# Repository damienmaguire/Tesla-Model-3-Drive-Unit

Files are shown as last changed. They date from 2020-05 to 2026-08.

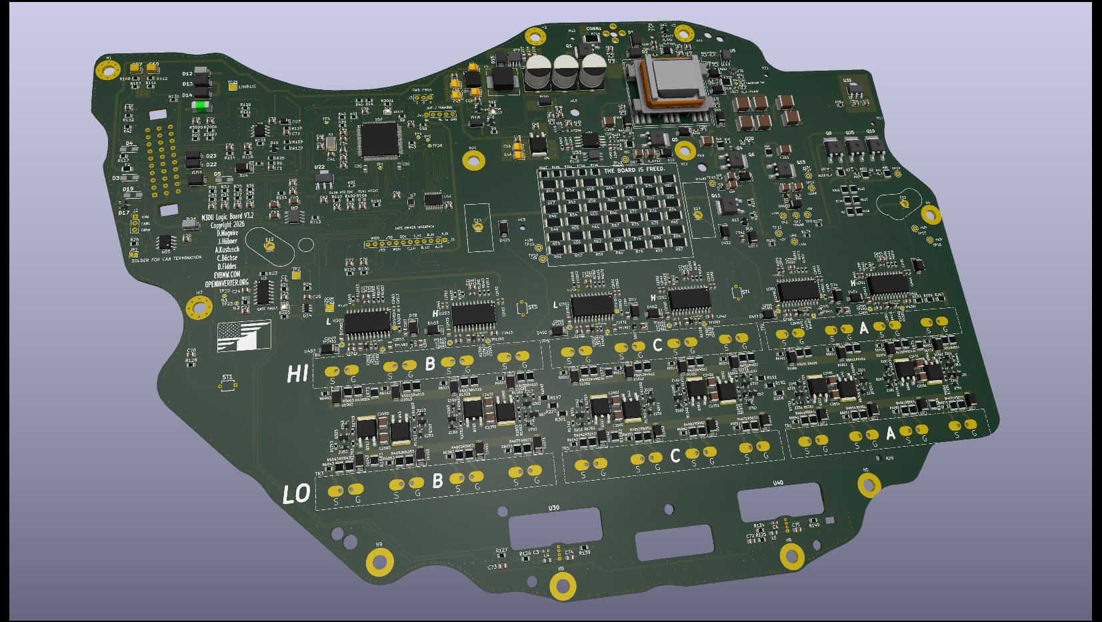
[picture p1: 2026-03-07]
Design/M3DU_BoardV3_2/M3DU_BoardV3_2.jpg

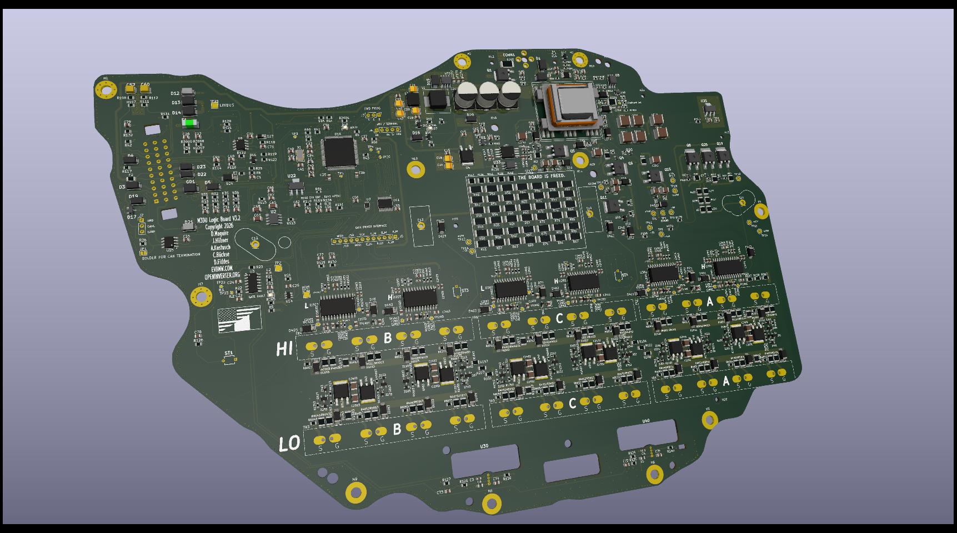
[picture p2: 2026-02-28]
Design/M3DU_BoardV3_2/Production/M3DU_BoardV3_2_3d.jpg

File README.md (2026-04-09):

# Tesla-Model-3-Drive-Unit
Open Source logic board for the Tesla Model 3 rear drive unit. PCB Files in DesignSpark 9 and Kicad 8 format.Based on the inverter designed by Johannes Heubner using FOC control.
<br>
Screenshot from 2025-01-08 18-51-52

<br>
13/03/20 : Added CAN logs from both CAN busses from the rear drive unit inverter powered on the bench.

04/05/20 : Added pdf schematic and board layout for the V1 logic board design. Untested as of this date. Given recent developments the design files will not be released at this time. For more information see : <br>
https://openinverter.org/forum/viewtopic.php?f=10&t=575

26/07/20 : After initial testing of V1 in a rear drive unit inverter some issues were found. V2 now released. Changes :

-Added resolver signal preconditioning circuit. Resolver signal needs to be amplified to 1v p-p and offset to 1.6v before feeding to the Tesla resolvver power amp.

-Added opamp to combine differential HV voltage measurement to unipolar.

-Deleted Tagconnect Jtag.

-Added 3v3 pin for single wire programming via st-link.

-Added solder jumper for optional single 5v power supply.

Please note design source files will be only available via Patreon for a period of time:

https://www.patreon.com/evbmw

02/10/20 : V2 board now fully tested in an M3 Rear drive unit and working very well on the bench.
<br>At this time I have decided to do a full opensource release of all design sources:)
<br>More updates and video to following including testing in a M3 front DU.

18/11/20 : Uploaded spreadsheet work in progress for mapping the pin assignments of the TMS320F28377D MCU.

21/11/20 : Discovered an eeprom on the back of the pcb. Logic analyser captures uploaded. All logic analyser captures made using Saleae logic. Free software available here :https://www.saleae.com/downloads/

02/12/20 : Big thanks to Colin Kidder (https://github.com/collin80) for the explanation of the STGAP1AS SPI gate driver traffic. PDF uploaded to the Gate SPI folder.

11/12/20 : Big thanks again to Colin Kidder (https://github.com/collin80) for the explanation of the TLF SPI power supply traffic. PDF uploaded to the TLF SPI folder.

08/02/21 : We have a new modboard : https://vimeo.com/509198907

08/05/21 : Added V3 modboard pdf schematic and board layout. Turns out Mr.Musk almost made a fool of me....again! 

18/10/21 : Added design files for USB to JTAG adapter board.

19/03/23 : Add first temp sensor calibration data

30/03/23 : Running : https://vimeo.com/809120859

15/08/24 : Added a very early schematic of the gate driver section for use in the PCB replacement project.

24/10/24 : Updated schematic of the gate driver power supply section for use in the PCB replacement project.

17/01/25 : Updated schematic and PCB layout to latest "complete" V1 version.

07/05/25 : First prototypes undergoing test.

board_jlc_powerup

28/05/25 : Testing continues. First motor spins :

https://youtu.be/JKbsiIRJ8mo

29/09/25 : V2 board now runs on HV : https://vimeo.com/1122427765

Added V3 Schematic and board layout.

26/10/25 : The V3 works. https://youtu.be/QYh9N8k0tf8

18/11/25 : First in car tests : https://youtu.be/6yrDDHRgUPQ also added pinout diagram.

03/12/25 : Updated 30 pin connector pinout and added a DXF of the OEM board derived from a laser scan.

01/02/26 : Uploaded V3.2 schematic and pcb layout. First order of boards on the way!

26/02/26 : Added capture of the gate driver SPI from a Model 3 front drive unit inverter.

28/02/26 : V3.2 board now undergoing testing.
V32_1

07/03/26 : I have made the decision to fully opensource the V3.2 design. Almost six years of work in here by myself and others so please respect that.

09/04/26 : An amazing contribution : https://github.com/jrbe/Tesla-Model-3-Current-Sensor-Block
           Prototypes on order.

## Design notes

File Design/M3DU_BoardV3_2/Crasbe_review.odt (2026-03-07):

M3 PCB Crasbe Review

personally, I'm not a big fan of SMD fuses. I can't tell from the screenshot, but if you have space (haha), it might be good to add an SMD fuse socket.

the value of the Zener diode D20 (7V) might be a bit high for the 3.3V rail.

the value of the inductor L3 is incorrect for the 3.3V rail, the datasheet says it should be 47µH.

the values of some capacitors do not follow the naming scheme: C124, C275, C282, C286, C334 have the value "0.1uF" while most use "100nF". this causes a BOM inconsistency.

some capacitors use symbols for polarized caps while they probably aren't polarized: C29, C30, C31, C32, C39, C40, C58, C59, C61, C62, C64, C66, C67, C69, C72, C73, C79.

(nitpicky) the schematic would be a bit easier to read if IC2 was mirrored.

typo in the "DC BUS DISCH AND VOLTAGE MEASURE" box: "HV Duscharge ..." instead of "HV Discharge ...".

in the "DC BUS DISCH AND VOLTAGE MEASURE" box: maybe you could add a dotted line or something to designate the HV and the isolated section more clearly.

not sure if that's the original Tesla design, but the "Motor Temp Sensor" voltage divider seems odd. assuming a 100k NTC, you'd have 0.275V at 25°C and something like 1.0V at 80°C. that's not using the full scale of the ADC and therefore reduces the resolution

general remark: you can set the direction of labels in KiCAD, that would make it easier to follow for signals like "SINB" and "ENC_A"

general remark: the ERC check in KiCAD will bonk you for not putting the blue "unused" crosses on usused pins. while it's not a good idea to put them on for example the microcontroller pins when you still might use them, it's good practice to put them on "NC" or "TEST" pins

for the PCB:

- TP12 and TP14 are quite close to the HV. even though they are on the "hot" side, I'd move them farther away from the resistors. As they are connected to the internal planes anyway, you can position them close to anywhere
- the isolation distance of the big resistor array to the "cold" side in general is on the small side
- TP2, TP4, TP5 are SMD test points, I'd change that to THT test points, there is enough space
- U3, U5, U303, U293, U302, U292, U301, U291, ... have adjacent pins that are connected and you connected them in the center of the pad. PCB assemblers often don't like that (both the Chinese and private persons) because it's hard to tell whether you have a short or it was intentionally connected. A better solution is the green trace on the upper right of picture [1]
- U3, U8, U31, U33, ... have traces leaving at a 90° angle from the pad. This is not good practise either (see picture [1] in the lower half)
- under/near U16 are three very small vias. There is enough space to make them the same size as all other vias. That might save some money (not sure if they are small enough to cost extra yet)
- the layout around the two step down converters U22 and U70 is not great. In order to minimize EMC, the area and current paths of the step downs has to be reduced. See [2]
- the length of the current sensor traces to the comparator might be an issue, especially since they are going past "noisy" areas. I'm not sure if it would be better to place LM2091 closer to the sensors, but then you'd have long lines for the OCURLIM_POS and OCURLIM_NEG lines. However these are "digital" until they are filtered, while the current signals are analog

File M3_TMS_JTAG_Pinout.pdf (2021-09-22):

# Tesla Model 3 Inverter JTAG Connection

Board Connector: Hirose DF20F-10DP-1V(55)
Cable Connector Shell: Hirose DF20A-10DS-1C
Cable Connector Pins: Hirose DF20F-2830SCFA

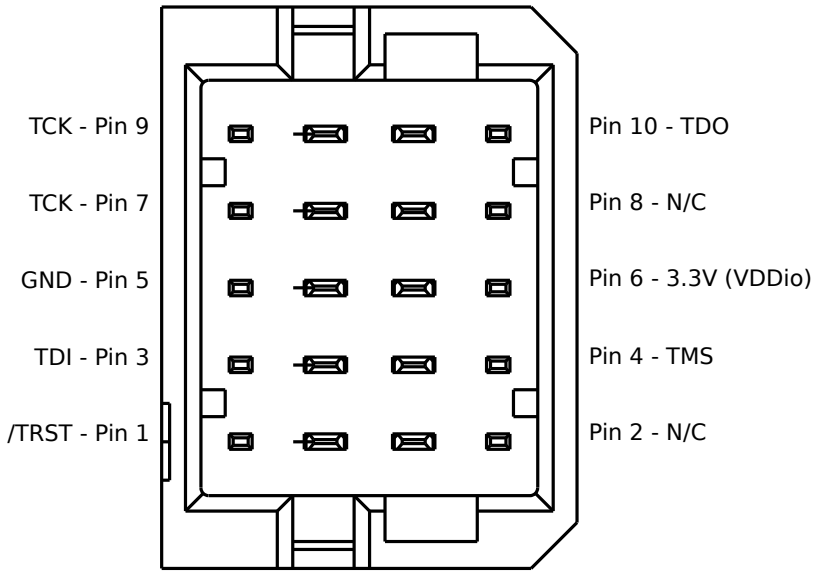
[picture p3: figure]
TCK - Pin 9; TCK - Pin 7; Pin 10 - TDO; Pin 8 - N/C; GND - Pin 5; TDI - Pin 3; /TRST - Pin 1; Pin 6 - 3.3V (VDDio); Pin 4 - TMS; Pin 2 - N/C

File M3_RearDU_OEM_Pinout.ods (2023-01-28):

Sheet: Main_Conn
Model 3 X090 Rear Inverter Connector OEM
Pin | Signal | Tesla Wiring Harness Colour | Connector Pin Numbering
1 | Proximity Digital in (charge port) | White | (looking at wiring harness connector,
2 | Vehicle CAN L | Blue | cable exiting to the bottom)
3 | Switched +12v | Yellow
4 | HVIL OUT | White | 10 | 20 | 30
5 | Accel 2 Ground | Violet | 9 | 19 | 29
6 | Accel 1 Ground | Yellow | 8 | 18 | 28
7 | Resolver SIN - | Red | 7 | 17 | 27
8 | Resolver COS + | Violet | 6 | 16 | 26
9 | N/C |  | 5 | 15 | 25
10 | LIN Oil Pump status | Yellow | 4 | 14 | 24
11 | Brake NO Digital in | Red | 3 | 13 | 23
12 | Vehicle CAN H | Yellow | 2 | 12 | 22
13 | Ground | Black | 1 | 11 | 21
14 | +5v Out 2 | Brown
15 | +5v Out 1 | Red
16 | Resolver EXC - | Black
17 | Resolver SIN + | Green
18 | Stator Temp - | Grey
19 | N/C
20 | PRTY – CAN L | White
21 | Brake NC Digital in | Brown
22 | Unswitched +12v | Violet
23 | HVIL IN | Red
24 | Accel 2 | Green
25 | Accel 1 | Grey
26 | Resolver EXC+ | Yellow
27 | Resolver COS - | Blue
28 | Stator Temp + | White
29 | N/C
30 | PRTY – CAN H | Blue

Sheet: Oil_Pump
Model 3 X092 Rear InverterOil Pump Connector OEM
Pin | Signal | Tesla Wiring Harness Colour | Connector Pin Numbering
1 | +12V In | Red | (looking at wiring harness connector,
2 | LIN | Yellow | cable exiting to the bottom)
3 | GND | Black
 |  |  | 3
 |  |  | 2
 |  |  | 1

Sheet: Resolver
Model 3 X091 Rear Inverter Resolver Connector OEM
Pin | Signal | Tesla Wiring Harness Colour | Connector Pin Numbering
1 | Temp+ | White | (looking at wiring harness connector,
2 |  |  | cable exiting to the bottom)
3 | Exc+ | Yellow
4 | Sin+ | Green
5 | Cos+ | Vilot
6 | Temp- | Grey
7
8 | Exc- | Black
9 | Sin- | Red | 5 | 10
10 | Cos- | Blue | 4 | 9
 |  |  | 3 | 8
 |  |  | 2 | 7
 |  |  | 1 | 6

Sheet: Throttle
Model 3 X167 Rear Inverter Throttle Connector OEM
Pin | Signal | Tesla Wiring Harness Colour | Connector Pin Numbering
1 | +5V Accel2 | Brown | (looking at wiring harness connector,
2 | Accel Sig 2 | Green | cable exiting to the bottom)
3 | Gnd Accel 2 | Vilot
4 | GND Accel 1 | Yellow
5 | Accel Sig 1 | Grey
6 | +5V Accel 1 | Red
 |  |  | 6
 |  |  | 5
 |  |  | 4
 |  |  | 3
 |  |  | 2
 |  |  | 1

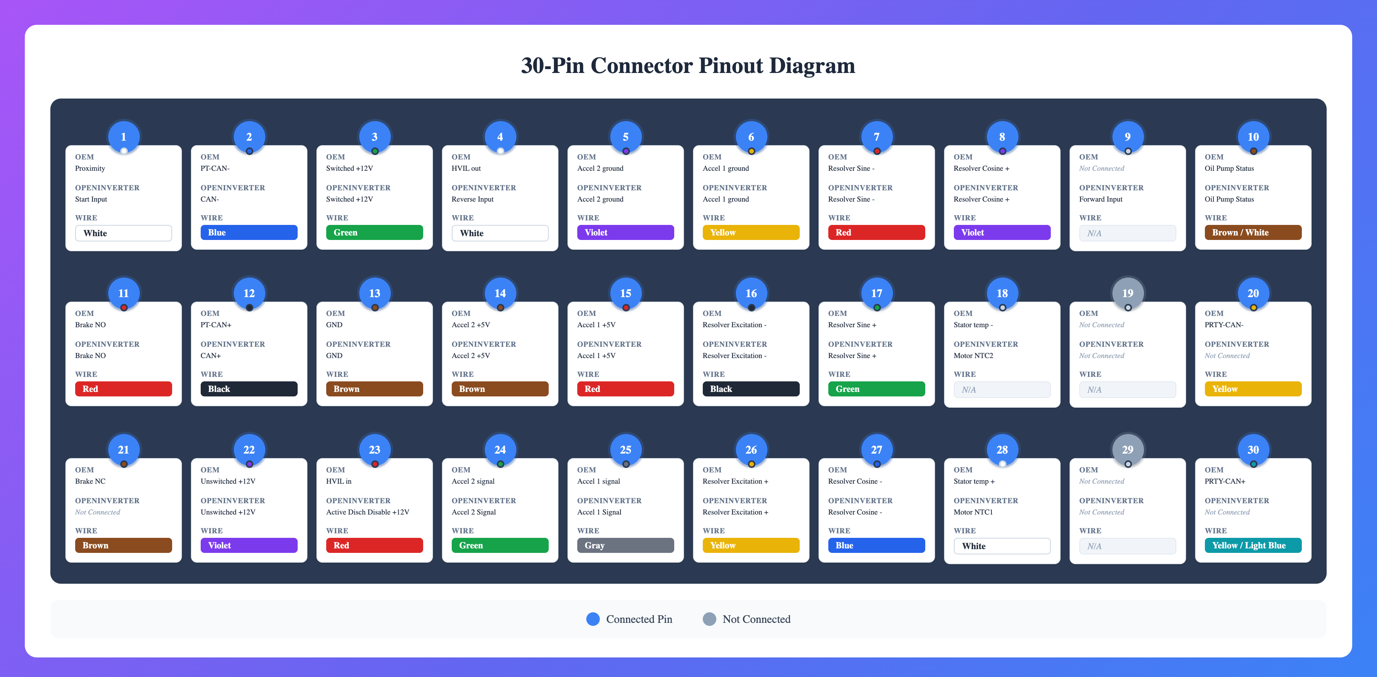
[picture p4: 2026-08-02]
OI_Pinout.png

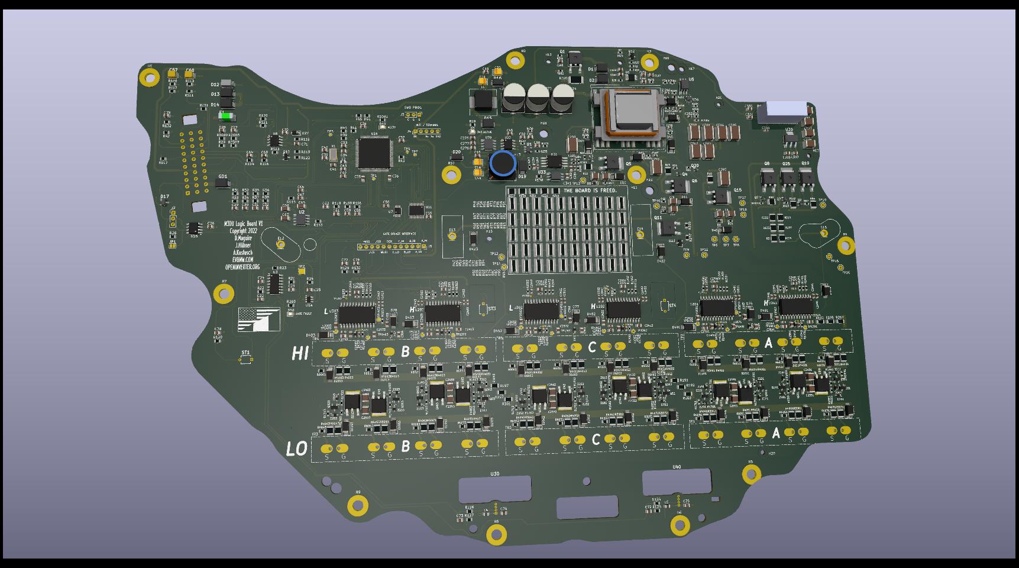
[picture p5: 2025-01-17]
Design/M3DUBoard_V1.jpg

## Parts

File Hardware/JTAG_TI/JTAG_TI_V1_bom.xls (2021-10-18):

Comment | Designator | Footprint | LCSC Part #
93LC56BT-I/SN | IC4 | SOIC-8_3.9x4.9x1.27P | C6164
AMS117-3.3V | IC2 | SOT-223 | C6186
36pF | C9,C10 | C0805 | C1816
3u3 | C6 | C0805 | C159781
4u7 | C7,C8 | C0805 | C98195
10uF | C1,C12 | C0805 | C15850
0.1uF | C3,C4,C5,C11 | C0805 | C49678
FT2232HL-REEL | IC1 | LQFP-64_10.0x10.0x0.5P | C27882
12MHz | Y1 | SMD-CRY-3.8x13.5_2P | C111117
RED LED | LED1,LED2,LED3 | LED_0805 | C84256
1KΩ | R5,R17 | 0805_R | C17513
2.2KΩ | R9 | 0805_R | C17520
10KΩ | R8 | 0805_R | C17414
12KΩ | R4 | 0805_R | C17444
680Ω | R1,R2,R3 | 0805_R | C17798
100UF 6.3V | C2 | CASE-B_3528 | C16133
CG0603MLC-05E | R6,R7 | 0603 | C20965
MH2029-300Y | L1,L2 | 0805_L | C281113

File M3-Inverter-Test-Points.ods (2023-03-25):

Test Point | Location | Description | Purpose
TP1 |  |  | Unknown | Key
TP2 |  |  | Unknown | Unknown | Nothing understood about this TP yet
TP3 |  |  | Unknown | Mapped | Location identified and something about the signal is known
TP4 |  |  | Unknown | Known | The purpose and signal on the TP is fully known and documented
TP5 |  |  | Unknown
TP6 |  |  | Unknown
TP7 |  |  | Unknown
TP8 |  |  | Unknown
TP9 |  |  | Unknown
TP10 |  |  | Unknown
TP11 |  |  | Unknown
TP12 |  |  | Unknown
TP13 |  |  | Unknown
TP14 |  |  | Unknown
TP15 |  |  | Unknown
TP16 |  |  | Unknown
TP17 |  |  | Unknown
TP18 |  |  | Unknown
TP19 |  |  | Unknown
TP20 |  |  | Unknown
TP21 |  |  | Unknown
TP22 |  |  | Unknown
TP23 |  |  | Unknown
TP24 |  |  | Unknown
TP25 |  |  | Unknown
TP26 |  |  | Unknown
TP27 | MCU/JTAG | SN74LVC8T245 /OE PWM GATE DRIVER BUFFER CONTROL | Known
TP28 | T1 Gate PSU | GATE DRIVE PSU READY opto output (active low) | Known
TP29 |  |  | Unknown
TP30 | PMIC | 3.3V VDD-IO | Known
TP31 |  |  | Unknown
TP32 | PMIC | Observed with solid 3.3V | Mapped
TP33 |  |  | Unknown
TP34 | PMIC | Observed with 5.5V | Mapped
TP35 | PMIC | Observed with 5V | Mapped
TP36 |  |  | Unknown
TP37 |  |  | Unknown
TP38 | PMIC | Observed with 0.5V | Mapped
TP39 |  |  | Unknown
TP40 |  |  | Unknown
TP41 | PMIC | Observed with 1.17V likely Vcore for MCU | Mapped
TP42 |  |  | Unknown
TP43 | MCU | GPIO83 GATE DRIVE PSU READY (active low) | Known
TP44 |  |  | Unknown
TP45 |  |  | Unknown
TP46 |  |  | Unknown
TP47 |  |  | Unknown
TP48 |  |  | Unknown
TP49 |  |  | Unknown
TP50 | MCU | GPIO1_EPWM1B_SCLA | Mapped
TP51 |  |  | Unknown
TP52 |  |  | Unknown
TP53 |  |  | Unknown
TP54 |  |  | Unknown
TP55 |  |  | Unknown
TP56 |  |  | Unknown
TP57 |  |  | Unknown
TP58 | Phase C U292 | Gate Drive Shutdown (/SD) | Known
TP59 | MCU | GPIO3_EPWM2B_SCLB | Mapped
TP60 |  |  | Unknown
TP61 |  |  | Unknown
TP62 |  |  | Unknown
TP63 |  |  | Unknown
TP64 |  |  | Unknown
TP65 |  |  | Unknown
TP66 | MCU | GPIO69 | Mapped
TP67 | MCU | GPIO70 | Mapped
TP68 | MCU | GPIO71 | Mapped
TP69 | MCU | GPIO73 | Mapped
TP70 | MCU | GPIO80 | Mapped
TP71 | MCU | GPIO79 | Mapped
TP72 | MCU | GPIO81 | Mapped
TP73 | MCU | GPIO82 ENABLE ISOLATED GATE DRIVE PSU | Known
TP74 |  |  | Unknown
TP75 | MCU | GPIO85_SCIRXDA | Mapped
TP76 | MCU | GPIO86_SCITXDB | Mapped
TP77 | MCU | GPIO87_SCIRXDB | Mapped
TP78 | MCU | GPIO88 | Mapped
TP79 | MCU | GPIO89_SCITXDC | Mapped
TP80 | MCU | GPIO90_SCIRXDC | Mapped
TP81 | MCU | GPIO91_SDAA | Mapped
TP82 | MCU | GPIO92_SCLA | Mapped
TP83 | MCU | GPIO93_SCITXDD | Mapped
TP84 | MCU | GPIO94_SCIRXDD | Mapped
TP85 |  |  | Unknown
TP86 |  |  | Unknown
TP87 |  |  | Unknown
TP88 |  |  | Unknown
TP89 |  |  | Unknown
TP90 |  |  | Unknown
TP91 |  |  | Unknown
TP92 |  |  | Unknown
TP93 |  |  | Unknown
TP94 |  |  | Unknown
TP95 |  |  | Unknown
TP96 |  |  | Unknown
TP97 |  |  | Unknown
TP98 |  |  | Unknown
TP99 |  |  | Unknown
TP100 | MCU | GPIO0_EPWM1A Resolver Exciter 10kHz output | Known
TP101 | PMIC | 12V vehicle supply less 0.4V Schottky diode drop | Mapped
TP102 |  |  | Unknown
TP103 |  |  | Unknown
TP104 |  |  | Unknown
TP105 |  |  | Unknown
TP106 | T1 Gate PSU | Gate PSU Running Output (Active Low) | Known
TP107 |  |  | Unknown
TP108 |  |  | Unknown
TP109 |  |  | Unknown
TP110 |  |  | Unknown
TP111 |  |  | Unknown
TP112 |  |  | Unknown
TP113 |  |  | Unknown
TP114 |  |  | Unknown
TP115 |  |  | Unknown
TP116 |  |  | Unknown
TP117 |  |  | Unknown
TP118 |  |  | Unknown
TP119 |  |  | Unknown
TP120 |  |  | Unknown
TP121 |  |  | Unknown
TP122 |  |  | Unknown
TP123 |  |  | Unknown
TP124 |  |  | Unknown
TP125 |  |  | Unknown
TP126 |  |  | Unknown
TP127 |  |  | Unknown
TP128 |  |  | Unknown
TP129 |  |  | Unknown
TP130 |  |  | Unknown
TP131 |  |  | Unknown
TP132 |  |  | Unknown
TP133 | U25 | 3V pk-pk ramp aligned with resolver exciter square wave | Known
TP134 | U19 | Resolver exciter output | Known
TP135 |  |  | Unknown
TP136 |  |  | Unknown
TP137 |  |  | Unknown
TP138 |  |  | Unknown
TP139 |  |  | Unknown
TP140 |  |  | Unknown
TP141 |  |  | Unknown
TP142 |  |  | Unknown
TP143 |  |  | Unknown
TP144 |  |  | Unknown
TP145 |  |  | Unknown
TP146 |  |  | Unknown
TP147 |  |  | Unknown
TP148 |  |  | Unknown
TP149 |  |  | Unknown
TP150 |  |  | Unknown
TP151 | Gate HV DC-DC | Phase A H ISOGND | Unknown
TP152 |  |  | Unknown
TP153 |  |  | Unknown
TP154 |  |  | Unknown
TP155 | Gate HV DC-DC | Phase C H ISOGND | Known
TP156 |  |  | Unknown
TP157 | Gate HV DC-DC | Phase A H VH (+20V) | Known
TP158 | Gate HV DC-DC | Phase A H VL (-5V) | Known
TP159 | Gate HV DC-DC | Phase C H VH (+20V) | Known
TP160 |  |  | Unknown
TP161 | Gate HV DC-DC | Phase C H VL (-5V) | Known
TP162 |  |  | Unknown
TP163 |  |  | Unknown
TP164 |  |  | Unknown
TP165 | Gate DC-DC | Phase B H VL (-5V) | Known
TP166 |  |  | Unknown
TP167 |  |  | Unknown
TP168 |  |  | Unknown
TP169 |  |  | Unknown
TP170 |  |  | Unknown
TP171 |  |  | Unknown
TP172 |  |  | Unknown
TP173 |  |  | Unknown
TP174 |  |  | Unknown
TP175 |  |  | Unknown
TP176 |  |  | Unknown
TP177 |  |  | Unknown
TP178 |  |  | Unknown
TP179 | Gate DC-DC | Phase B H ISOGND | Known
TP1361 | Phase A L | U301 ~Diag1 Fault output | Known
TP1362 | Phase C L | U302 ~Diag1 Fault output | Known
TP1363 | Phase B L | U303 ~Diag1 Fault output | Known
TP1391 | Phase A H | U291 GOFF | Known
TP1411 | Phase A H | U291 ISOGND | Known
TP291 | Phase A H | U291 DESAT | Known
TP1491 | Phase A L | U301 GOFF | Known
TP1441 | Phase A L | U301 ISOGND | Known
TP1431 | Phase A L | U301 DESAT | Known
TP1451 | Phase A L | U301 ASC – Asynchronous Stop | Known
TP1392 | Phase C H | U292 GOFF | Known
TP1412 | Phase C H | U292 ISOGND | Known
TP292 | Phase C H | U292 DESAT | Known
TP1492 | Phase C L | U302 GOFF | Known
TP1432 | Phase C L | U302 ISOGND | Known
TP1442 | Phase C L | U302 DESAT | Known
TP1452 | Phase C L | U302 ASC – Asynchronous Stop | Known
TP1392 | Phase B H | U293 GOFF | Known
TP1412 | Phase B H | U293 ISOGND | Known
TP292 | Phase B H | U293 DESAT | Known
TP1492 | Phase B L | U303 GOFF | Known
TP1432 | Phase B L | U303 ISOGND | Known
TP1442 | Phase B L | U303 DESAT | Known
TP1452 | Phase B L | U303 ASC – Asynchronous Stop | Known

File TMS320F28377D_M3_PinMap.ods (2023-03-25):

PIN MAP FOR TI TMS320F28377D MCU USED ON TESLA MODEL 3 DRIVE UNIT
PIN NUMBER | ID | FUNCTION | COMMENTS
1 | GPIO10 | PWM C HIGH | GATE DRIVE C HIGH. HAS PULLDOWN TO GND. MUST BE DRIVEN ON. EPWM6A (HRPWM-capable)
2 | GPIO11 | PWM C LOW | GATE DRIVE C LOW. HAS PULLUP TO 3V3. MUST BE DRIVEN LOW FOR OFF. EPWM6B (HRPWM-capable)
3 | VddIO
4 | GPIO12 | PWM B HIGH | EPWM7A (HRPWM-capable)
5 | GPIO13 | PWM B LOW | EPWM7B (HRPWM-capable)
6 | GPIO14
7 | GPIO15 | BRAKE N/O | BRAKE NORMALLY OPEN. 3.8V OPEN , 0.27V CLOSED
8 | GPIO16 | TLF35584 SPI MOSI | TLF35584 DC SUPPLY IC SPI COMMS. APPROX 0.6SEC AFTER LOSS OF SPI SS1 AND SS2 GO LOW
9 | GPIO17 | TLF35584 SPI MISO
10 | GPIO18 | TLF35584 SPI CLOCK
11 | VddIO | 3V3 | NOTE ALL 3V3 LINES ARE COMMON
12 | GPIO19 | TLF35584 SPI CS
13 | GPIO20
14 | GPIO21
15 | VddIO | 3V3
16 | VDD | 1V2 | NOTE ALL 1V2 LINES ARE COMMON
17 | GPIO99
18 | GPIO8 | PWM A HIGH | EPWM5A (HRPWM-capable)
19 | GPIO9 | PWM A LOW | EPWM5B (HRPWM-capable)
20 | VddIO | 3V3
21 | VDD | 1V2
22 | GPIO22 | EEPROM PIN 6 | 25LC256 EEPROM 2MHZ SPI CLOCK
23 | GPIO23 | EEPROM PIN 1 | 25LC256 EEPROM SPI CS
24 | GPIO24 | EEPROM PIN 5 | 25LC256 EEPROM SPI MOSI
25 | GPIO25 | EEPROM PIN 2 | 25LC256 EEPROM SPI MISO
26 | VddIO | 3V3
27 | GPIO26 | BRAKE N/C | BRAKE NORMALLY CLOSED. 3.8V OPEN , 0.27V CLOSED
28 | GPIO27 | CP PROX | CHARGE PORT PROXIMITY SIGNAL. LOW=1
29 | ADCINC4 | 12V SUPPLY MEASURE | MEASURES 12V SUPPLY VOLTAGE VIA THIS ADC INPUT PIN (205.88 per volt)
30 | ADCINC3
31 | ADCINC2 | PHASE B/A CURRENT | This pin reacts to both A and B current sensors. Possible max of the two?
32 | Vrefloc | GND | ADC LOW REF. GROUND
33 | Vrefloa | GND | ADC LOW REF. GROUND
34 | Vssa | GND | ANALOG GROUND PIN
35 | Vrefhic | 3V3 | ADC-C high reference
36 | Vdda | 3V3 | 3.3-V analog powerpins
37 | Vrefhia | 3V3 | ADC-A high reference
38 | ADCINA5 | HVIL SENSE | HVIL CURRENT SENSE. 20MA = 86mV
39 | ADCINA4 | PHASE A CURRENT SENSOR | 1.65V=0A
40 | ADCINA3 | THROTTLE 2 | ANALOG THROTTLE 2 0-3V3
41 | ADCINA2
42 | ADCINA1
43 | ADCINA0 | RESOLVER SINE | RESOLVER FEEDBACK 1
44 | ADCIN14
45 | ADCIN15
46 | ADCINB0
47 | ADCINB1 | RESOLVER COSINE | RESOLVER FEEDBACK 2
48 | ADCINB2 | DC LINK VOLTAGE | ISOLATED DC LINK VOLTAGE 0-3V3
49 | ADCINB3 | MULTIPLEXED TEMPERATURES | 6 MULTIPLEXED TEMP READINGS,1MS PER SAMPLE
50 | Vreflob | GND | ADC LOW REF. GROUND
51 | Vreflod | GND | ADC LOW REF. GROUND
52 | Vssa | GND | ANALOG GROUND PIN
53 | Vrefhib | 3V3 | ADC-B high reference
54 | Vdda | 3V3 | 3.3-V analog powerpins
55 | Vrefhid | 3V3 | ADC-D high reference
56 | ADCIND0
57 | ADCIND1 | THROTTLE 1 | ANALOG THROTTLE 1 0-3V3
58 | ADCIND2 | PHASE B CURRENT SENSOR | 1.65V=0A
59 | ADCIND3
60 | ADCIND4 | EXCITER MONITOR ANALOG I/P | ADC INPUT USED TO MONITOR THE RESOLVER EXCITER
61 | Vdd | 1V2
62 | Vddio | 3V3
63 | GPIO30 | 4051 TEMP MUX S1 | TEMPERATURE MUX SELECT LINES
64 | GPIO28
65 | GPIO29
66 | GPIO31 | 4051 TEMP MUX S2 | TEMPERATURE MUX SELECT LINES
67 | GPIO32 | 4051 TEMP MUX S3 | TEMPERATURE MUX SELECT LINES
68 | Vddio | 3V3
69 | GPIO33
70 | GPIO34
71 | GPIO35
72 | Vdd3vfl |  | 3.3-V Flash power pin
73 | FLT1 | RESERVED | FLASH TEST PIN. LEAVE UNCONNECTED.
74 | FLT2 | RESERVED | FLASH TEST PIN. LEAVE UNCONNECTED.
75 | Vddio | 3V3
76 | Vdd | 1V2
77 | TDI | JTAG TDI | JTAG PINS
78 | TDO | JTAG TDO
79 | /TRST | JTAG /TRST
80 | TMS | JTAG TMS
81 | TCK | JTAG TCK
82 | Vddio | 3V3
83 | GPIO36
84 | GPIO37
85 | GPIO38 | /SD ALL GATE DRIVERS | PULSE LOW TO ENABLE GATE DRIVERS
86 | GPIO39
87 | GPIO40
88 | Vddio | 3V3
89 | GPIO41
90 | GPIO48 | LIN TxD | OIL PUMP LIN COMMS. OIL PUMP CONTROLLER=Onsemi LV8907
91 | Vddio | 3V3
92 | ERRORSTS | ERROR STATUS | ERROR STATUS OUTPUT PIN. NEAR 0V DURING RUN AND RESET.
93 | GPIO49 | LIN RxD | OIL PUMP LIN COMMS
94 | GPIO50 | GATE SPI MOSI | GATE DRIVER SPI
95 | GPIO51 | GATE SPI MISO | GATE DRIVER SPI
96 | GPIO52 | GATE SPI CLK | GATE DRIVER SPI CLOCK
97 | GPIO53 | GATE SPI CS | ALL GATE SPI CS TIED TOGETHER
98 | GPIO54
99 | Vddio | 3V3
100 | GPIO55 | EEPROM 3 CS | UNPOPULATED EEPROM SPI CHIP SELECT
101 | GPIO56 | EEPROM 2 CS | UNPOPULATED EEPROM SPI CHIP SELECT
102 | GPIO57
103 | GPIO58
104 | GPIO59
105 | GPIO60
106 | Vddio | 3V3
107 | GPIO61
108 | GPIO62
109 | GPIO63
110 | GPIO64
111 | GPIO65 | TLF35584 INT | TLF35584 DC SUPPLY IC INTERRUPT
112 | GPIO66
113 | GPIO44
114 | Vddio | 3V3
115 | GPIO45
116 | Vddio | 3V3
117 | Vdd | 1V2
118 | GPIO133 | GATE DRIVER /DIAG1 | ALL GATE DRIVERS /DIAG1 PINS TIED TOGETHER AND TO THIS PIN AND RED LED AT B LOW IC.LOW=FAULT.
119 | VREGENZ | NOT SUPPORTED | TIE TO VDDIO AS PER DATASHEET
120 | Vddosc | 3V3 XTAL SUPPLY
121 | X2 | 10MHZ XTAL PIN 1
122 | Vssosc | GND XTAL SUPPLY
123 | X1 | 10MHZ XTAL PIN 2
124 | /XRS | EXTERNAL RESET | PULL LOW TO RESET DEVICE
125 | Vddosc | 3V3 XTAL SUPPLY
126 | Vdd | 1V2
127 | Vddio | 3V3
128 | GPIO46
129 | GPIO47
130 | GPIO42
131 | GPIO43
132 | GPIO67
133 | GPIO68
134 | GPIO69
135 | GPIO70
136 | GPIO71
137 | Vdd | 1V2
138 | Vddio | 3V3
139 | GPIO72 | RED LED | FLASHING LED, PULL LOW TO TURN LED ON. BOOT MODE PIN 1
140 | GPIO73
141 | GPIO74
142 | GPIO75
143 | GPIO76
144 | GPIO77
145 | GPIO78 | 74245 /OE ENABLE CONTROL | SN74LVC8T245 PWM GATE DRIVER BUFFER CONTROL OF /OE LINE. /OE ASSERTED IF : GPIO78=1 , TLF35584 PIN 10 SS2 =1 AND ISOLATED GATE DRIVER SUPPLY IS ON AND POWER GOOD SIGNAL =1.
146 | GPIO79
147 | Vddio | 3V3
148 | GPIO80
149 | GPIO81
150 | GPIO82 | GATE PSU ENABLE | ENABLE ISOLATED GATE DRIVE PSU
151 | GPIO83 | GATE PSU READY | ISOLATED GATE DRIVE PSU READY. ACTIVE LOW
152 | Vddio | 1V2
153 | Vdd | 3V3
154 | GPIO84 | GREEN LED | FLASHING LED, PULL LOW TO TURN LED ON. BOOT MODE PIN 0
155 | GPIO85
156 | GPIO86
157 | GPIO87
158 | Vdd | 1V2
159 | Vddio | 3V3
160 | GPIO0 | EXC SQ WAVE O/P | 10KHZ SQUARE WAVE,50% DUTY,3V3 SWING. THIS GENERATES THE RESOLVER EXCITER SINE!
161 | GPIO1
162 | GPIO2
163 | GPIO3
164 | GPIO4 | VEHICLE CAN Tx | VEHICLE CAN BUS, 500K BAUD
165 | GPIO5 | VEHICLE CAN Rx
166 | GPIO6 | PARTY CAN Tx | PRIVATE CAN BUS, 500K BAUD
167 | GPIO7 | PARTY CAN Rx
168 | Vddio | 3V3
169 | Vdd | 1V2
170 | GPIO88
171 | GPIO89
172 | GPIO90
173 | GPIO91
174 | GPIO92
175 | GPIO93
176 | GPIO94
 |  | HVIL / DC LINK DISCHARGE OPERATION | DC BUS DISCHARGE RESISTORS ARE CONTROLLED BY THE HVIL CIRCUIT VIA OPTO U33 (ACPL-M49T). WHEN HVIL PRESENCE IS DETECTED , DC BUS DISCHARGE IS REMOVED. HVIL IS A CURRENT LOOP SUPPLIED EXTERNALLY VIA PINS 4 AND 23 ON THE LV CONNECTOR. MINIMUM HVIL CURRENT = 15mA ,MAXIMUM HVIL CURRENT =24mA , NOMINAL =20mA.

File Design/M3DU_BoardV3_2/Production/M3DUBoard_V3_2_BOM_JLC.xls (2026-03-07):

Comment | Designator | Footprint | JLCPCB Part#
10R | R5061,R5032,R5031,R5043,R5013,R5011,R5041,R5022,R5063,R5052,R5072,R5033,R5062,R5051,R5021,R5071,R5023,R5012,R5002,R5042,R5053,R5001,R5003,R5073 | R1210 | C44451
10uF | C68,C63,C65 | C1206 | C13585
2.2uF | C12,C9,C13,C11,C14,C10 | C1210 | C55151
0.56R | R6011,R6031,R6073,R6021,R6001,R6003,R6042,R6032,R6061,R6052,R6041,R6071,R6051,R6053,R6062,R6072,R6063,R6002,R6023,R6043,R6012,R6022,R6033,R6013 | R0805 | C2934268
4R7 | R20 | R0603 | C23164
12R | R4053,R4052,R4013,R4012,R4003,R4072,R4002,R4001,R4032,R4061,R4033,R4043,R4071,R4062,R4063,R4042,R4023,R4041,R4073,R4021,R4051,R4011,R4031,R4022 | R1210 | C230026
JV/B5819WS | D413,D411,D472,D473,D702,D412,D471,D703,D701 | D_SOD-323 | C64886
100pF | C81,C82 | C0805 | C1790
220R | R111,R107,R112,R108 | R0805 | C17557
4K7 | R18,R14,R17 | R0603 | C23162
4K7 | R339 | R1812 | C621100
1uF | C32,C38,C36,C35,C79,C277,C74,C19,C55,C70,C77,C23,C27,C276,C15,C29,C28,C34,C31,C30,C22,C80,C78,C25,C306,C37,C341,C56,C45,C76,C75,C24,C1 | C0805 | C28323
27K | R1633,R1723,R1581,R1721,R1763,R1662,R1652,R1691,R1701,R1663,R1631,R1583,R1661,R1651,R1853,R1761,R1762,R1632,R1722,R1582,R1702,R1693,R1703,R1692,R9 | R0603 | C22967
3K9 | R46,R54,R74,R81,R61,R49,R72,R80,R51,R62,R76,R69,R63,R57,R73,R55,R67,R84,R85,R65,R78,R83,R87,R66,R75,R56,R52,R82,R77,R79,R53,R68,R71,R86,R47,R59,R58,R70,R64,R48,R50,R60 | R2512 | C723442
68uH | L1 | L_12x12mm_H8mm | C2452974
3uH | L3 | SMD,5.7x5.7mm | C2453144
1M | R191,R227,R193,R268,R196,R301,R267,R197,R192 | R1206 | C17927
680R | R1563,R1562,R1293,R1291,R1561,R1292,R19 | R0603 | C17798
1uF | C2501,C2581,C2363,C2503,C119,C301,C304,C2421,C2361,C2573,C2413,C2571,C2572,C2422,C2412,C2423,C2411,C2362,C2502 | C0805 | C28323
MMBT3904 | Q12,Q10,Q16,Q17 | SOT-23 | C181119
2H2/SS56 | D1072,D1043,D1061,D1032,D1022,D1023,D1053,D1002,D1052,D1041,D1021,D1071,D1033,D1042,D1011,D1073,D1051,D1013,D1003,D1031,D1062,D1012,D1063,D1001 | D_SMA | C18199562
1k | R1482,R1462,R1472,R1411,R1461,R1463,R1473,R1332,R1331,R1413,R7006,R1483,R1471,R1333,R175,R1412,R1481,R91 | R0603 | C21190
SS54B | D14,D15,D13 | DIOM5336X244N | C32513
4.7uF | C2402,C2403,C2693,C2723,C2702,C2703,C2701,C2692,C2401,C2722,C2691,C2721 | C0805 | C1779
33.2K | R28 | R0603 | C23003
1K5 | R37,R38,R34,R33,R6 | R0805 | C4310
3N0408/IPD50N04S4-08 | Q992,Q991,Q212,Q211,Q993,Q213 | TO-252-2 | C536772
8.2V | Z232,Z203,Z183,Z242,Z212,Z251,Z201,Z211,Z231,Z233,Z213,Z193,Z191,Z192,Z221,Z181,Z202,Z252,Z222,Z223,Z241,Z182,Z253,Z243 | D_SOD-323 | C22375294
ACPL-M49T-000E | U33,U5 | SOIC127P700X260-6N | C17448737
1nF | C73,C64,C72,C69,C71,C83 | C0805 | C46653
SS35 | D11,D40,D10 | D_SMA | C511856
4.7uF | C2432,C2592,C2491,C2431,C2492,C2593,C2351,C2493,C2353,C2591,C2352,C2433 | C1210 | C86052
1K6 | R254 | d1 | C22847
NJVMJD127T4G/NJVMJD128T4G | Q25,Q6,Q19,Q8,Q15,Q5 | NVD5117PLT4GVF01 | C556442
82pF | C296,C2551,C2451,C292,C2471,C287,C2513,C2453,C2512,C2343,C2452,C2461,C2483,C2482,C2473,C2462,C2463,C2481,C2472,C2341,C2342,C2393,C2553,C2552,C2511,C2392,C278,C2391 | C0603 | C1683
100uF 25V | C209 | CP_Elec_10x10 | C294509
80.6R | R272,R283,R238,R291 | R0603 | C23115
VN17/MURA160T3G/STTH112A | D493,D421,D481,D74,D491,D78,D482,D422,D492,D77,D423,D483 | D_SMA | C131297
10nF | C2,C3,C4,C282,C265 | C0603 | C57112
100nF | C2002,C2001,C2562,C264,C263,C2521,C2373,C2522,C2523,C2372,C2563,C2371,C2561,C2003 | C0603 | C14663
1SMA5935A | D2 | DO-214AC(SMA | C688905
2K | R7008 | R0603 | C22975
45P4LLF6 | Q983,Q42,Q43,Q982,Q41,Q981 | TO-252-2 | C2969806
BC857BT-7-F | Q2,Q9,Q4,Q20,Q7,Q3 | SOT50P160X90-3N | C507908
100R | R1512,R1513,R1642,R1451,R1713,R1641,R1533,R1711,R1531,R1452,R1643,R1712,R1532,R1453,R1511 | R0603 | C22775
74LVC1G10 | U14 | SOT-23-6 | C22356917
22nF | C286 | C0603 | C21122
22nF | C59,C67,C61,C66,C58,C62 | C0805 | C1729
25K | R203,R212 | R0603 | C25962
SG NMOS D/BSS169 | Q52,Q51,Q53 | SOT-23 | C5355491
10K | R22,R116,R129,R21,R119,R128,R130,R113,R115,R114,R1,R136,R237,R133,R235,R139,R140,R25,R8,R4,R5 | R0805 | C17414
OPA320AIDBVR | U1 | SOT95P280X145-5N | C92494
STGAP1BSTR | U291,U292,U301,U293,U302,U303 | SO-24 | C5267708
10uF | C262,C261,C33,C43,C307 | C0805 | C15850
G1/B5819WS | D62,D61,D53 | D_SOD-323 | C169530
3K3 | R122,R45,R2 | R0805 | C26010
75K | R327,R211,R134,R229,R246 | R1210 | C351890
100uF 6.3V | C57,C60,C44,C16,C20,C21,C46,C47 | CAPPM3528X210N | C16133
STM32F103VCTx | U16 | LQFP-100_14x14mm_P0.5mm | C8313
3K6 | R124,R126 | R0805 | C18359
TPS40210QDGQRQ1 | U6 | HVSSOP-10-EP-0.5mm | C363281
120R | R26 | R0805 | C17437
4K7 | R35,R31,R36,R23,R41,R32,R24,R7 | R0805 | C17673
82K | R137,R222,R135,R329,R223,R3 | R1210 | C174656
LD1086DT33TR | U4 | TO-252-2(DPAK) | C12051
1K | R29,R118,R265,R43,R2007,R39,R40,R2008,R3000,R123,R131,R132,R98 | R0805 | C17513
STPS2H100-Y | D54,D64,D63,D45 | D_SMA | C81548
4R99 | R99,R10,R102,R13,R12,R96 | R1210 | C5126236
2051-09-SM-RPLF | GD1 | DIOM5336X244N | C719173
1SMA5918A | D68 | DO-214AC(SMA) | C713624
330pF | C281 | C0805 | C1737
200pF | C128 | C0805 | C1724
470pF | C285 | C0805 | C77489
47nF | C161 | C0805 | C53134
BSS84AK | Q313,Q312,Q311,Q183,Q182,Q181 | SOT-23 | C7379993
SMAJ7.0A | D16,D20,D22,D23 | DIOM5026X229N | C693605
10uH | L5,L4,L2 | L_0805_2012Metric | C139245
5V1 | D9,D6,D8 | D_SOD-323 | C169484
35K6 | R201 | R0603 | C23147
100nF | C26,C41,C42,C124,C275 | C0805 | C49678
22K | R11,R97,R103,R100,R16,R15 | R0603 | C31850
LM2901 | U3 | SOIC-14_3.9x8.7mm_P1.27mm | C7932
BSS138 | Q301,Q321,Q303,Q302,Q322,Q323 | SOT-23 | C78284
15uF | C501,C503,C502,C500,C504,C505 | C2220 | C5795620
5K6 | R204 | R0603 | C4382
3.3uF | C283,C298,C290 | C1812 | C1021607
6K2 | R127,R125 | R0805 | C17767
2.2uF | C294,C293,C2583,C303,C2582,C300 | C0805 | C19110
JFC2410-0500TS | F1 | FUSC6126X280N | C2998202
1206L050/24WR | F2 | R1206 | C2154056
200R | R1593,R1592,R1591 | R0603 | C8218
XL1509-5.0E1 | U70 | SOIC127P600X175-8N | C61063
100K | R182 | R0603 | C25803
10R | R247,R248 | R0603 | C22859
470pF | C2443,C2441,C2442 | C0603 | C1620
BSS84 | Q23 | SOT-23 | C112238
22pF | C39,C40 | C0805 | C1804
TL432AQDBZRQ1/TL432AIL3T | U38 | SOT95P237X112-3N | C190215
X50328MSB2GI | X1 | Crystal_SMD_5032-2Pin_5.0x3.2mm | C242219
SN74LVC245APW | U11 | TSSOP-20_4.4x6.5mm_P0.65mm | C7848
0.01R | R205 | R2512 | C393070
TJA1021T | U8 | SOIC-8_3.9x4.9mm_P1.27mm | C128810
ACPL-C87A | U31 | SSO-8_6.8x5.9mm_P1.27mm_Clearance8mm | C691944
LED | D18,D58,D7 | LED_0805_2012Metric | C84256
1N5819 | D1 | DO-214AC(SMA) | C437199
100K | R257,R228 | R0805 | C149504
20R | R200 | R0603 | C17544
300K | R27 | R0603 | C23024
330R | R2001 | R0805 | C17630
47K | R44,R42 | R0805 | C17713
4K7 | R1681,R1671,R1682,R1672,R1683,R1673 | R1210 | C26060
SMAJ18CA | D12,D3,D4,D5,D19,D21,D24 | DIONM5127X229N | C118307
ESDCAN01-2BLY | D17 | SOT95P255X150-3N | C1976606
0R | R3213,R3211,R3212 | R0603 | C21189
TPS7B6950QDCYRQ1 | U35 | SOT-223-4 | C108469
18K | R30 | R0603 | C25985
2K2 | R120,R121,R138 | R0805 | C17520
74LVC3G17 | U7 | VSSOP-8-0.5mm | C26159247
IPD50N06S409ATMA2 | Q1 | IPD50N06S4-09-VB | C7428996
220uF 35V | C273,C274 | CP_Elec_10x10 | C970697
SN65HVD230 | U55 | SOIC-8_3.9x4.9mm_P1.27mm | C12084
39R | R253 | R0603 | C23154
FGD3N60LSDTM | Q11 | SVF6N60D | C68778
TDA2822D013TR | U2 | SOIC127P600X175-8N | C668663
1N4148W | D27 | D_SOD-123 | C2099
470R | R1852,R1851,R1653 | R0603 | C23179
0R | R117 | R0805 | C416123
3K9 | R141 | R0805 | C17614
1K8 | R109,R110 | R0805 | C17398
39K | R208 | R0603 | C23153
NCV8452STT3G | U22 | SOT223 | C477982
1SMA4744A | D56 | SMA | C19077482
50K | R173,R174,R186 | R0805 | C2828840
100R | R384 | R0805 | C17408
VGT22EPC-200S6A12 | T1 | DIP-18P,33x24.8mm | C17686734

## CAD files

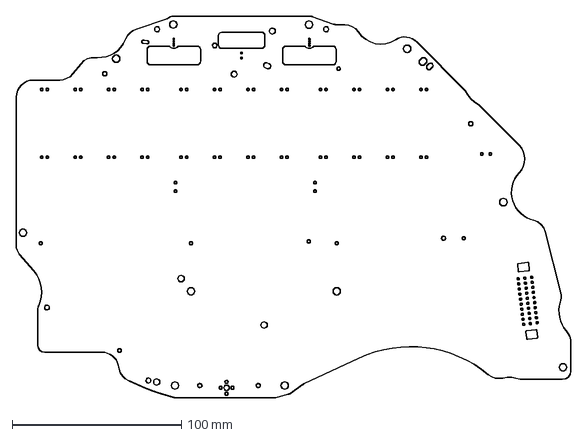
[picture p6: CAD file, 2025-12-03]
tesla model 3 inberter pcb v2.dxf
327.2 x 225.3 mm

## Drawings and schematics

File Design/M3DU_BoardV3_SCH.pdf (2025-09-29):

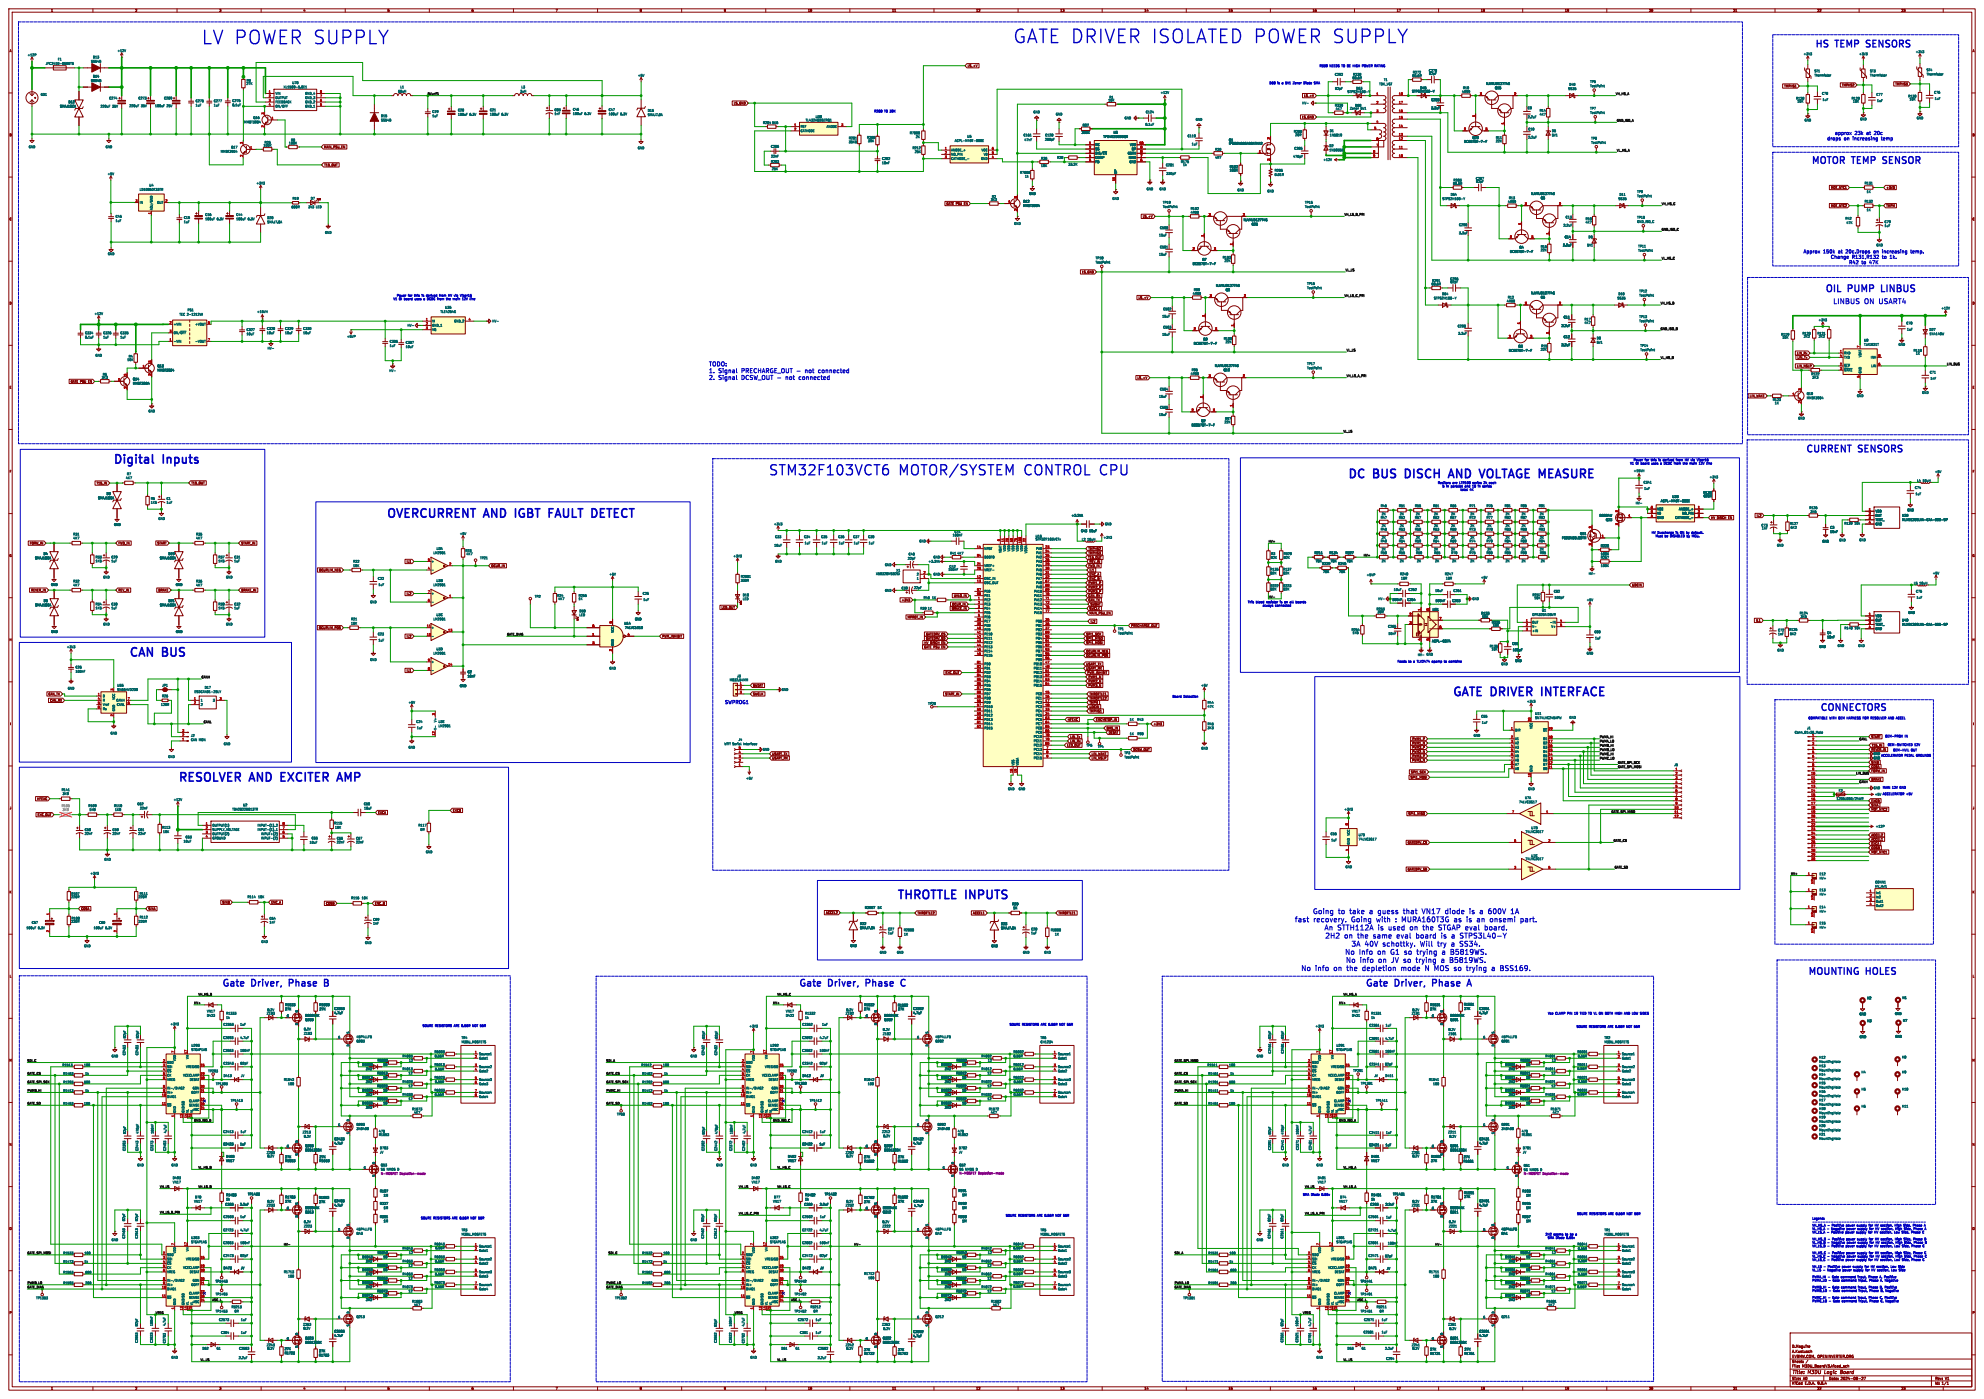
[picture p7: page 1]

R339 NEEDS TO BE HIGH POWER RATING
10 T1 TDK_VGT

D68 is a 5V1 Zener Diode SMA

Power for this is derived from HV via Viper16 V1 OI board uses a DCDC from the main 12V line TODO:
1. Signal PRECHARGE_OUT - not connected
2. Signal DCSW_OUT - not connected

STM32F103VCT6 MOTOR/SYSTEM CONTROL CPU

DC BUS DISCH AND VOLTAGE MEASURE

Resitors are LTR100 series 2k each

OVERCURRENT AND IGBT FAULT DETECT

HV Duscharge is ON by default. Must be DISABLED by MCU.

6 VDD 11 VDD 28 VDD 50 VSS 10 VDD 75 VSSA 19 VDD 100 VDDA 22 PA0
14 BOOT0
10nF NRST

Feeds to a TLV2474 opamp to combine GATE DRIVER INTERFACE

OEM-PROX IN CONNECTORS

ACCELERATOR PEDAL GROUNDS OEM-SWITCHED 12V OEM-HVIL OUT COMPATIBLE WITH OEM HARNESS FOR RESOLVER AND ACCEL Gate Driver, Phase A

RESOLVER AND EXCITER AMP

Going to take a guess that VN17 diode is a 600V 1A
fast recovery. Going with : MURA160T3G as is an onsemi part.

An STTH112A is used on the STGAP eval board.
2H2 on the same eval board is a STPS3L40-Y

3A 40V schottky. Will try a SS34.
No Info on G1 so trying a B5819WS.
No info on JV so trying a B5819WS.

2H2 seems to be a SMA Diode 0.55v Gate Driver, Phase C

Vce CLAMP PIN 19 TIED TO VL ON BOTH HIGH AND LOW SIDES

SOURE RESISTORS ARE 0.56R NOT 56R

1 GNDISO 13 VH 17 VL 14 VL 23 VREGISO 15 VCECLAMP 19 DESAT 18 GON 20 GOFF 21 CLAMP 22 SENSE 16 ASC 24 U293 STGAP1AS

1 GNDISO 13 VH 17 VL 14 VL 23 VREGISO
2 SDI 3 ~{CS} 4 CK
TP292 SDO

TP1411 TP1391 SDO

SDO 2 SDI 3 ~{CS} 4 CK 5 VREG 6

H14 MountingHole H13 MountingHole H19 MountingHole H15 MountingHole

1 GNDISO 13 VH 17 VL 14 VL 23 VREGISO 15 VCECLAMP 19 DESAT 18 GON 20 GOFF 21 CLAMP 22 SENSE 16 ASC 24 U303 STGAP1AS C2422 1uF D482 VN17 C2003 100nF R1851

8 TR5 M3DU_MOSFETS

8 TR1 M3DU_MOSFETS

SDO

Id: 1/1 Title: M3DU Logic Board

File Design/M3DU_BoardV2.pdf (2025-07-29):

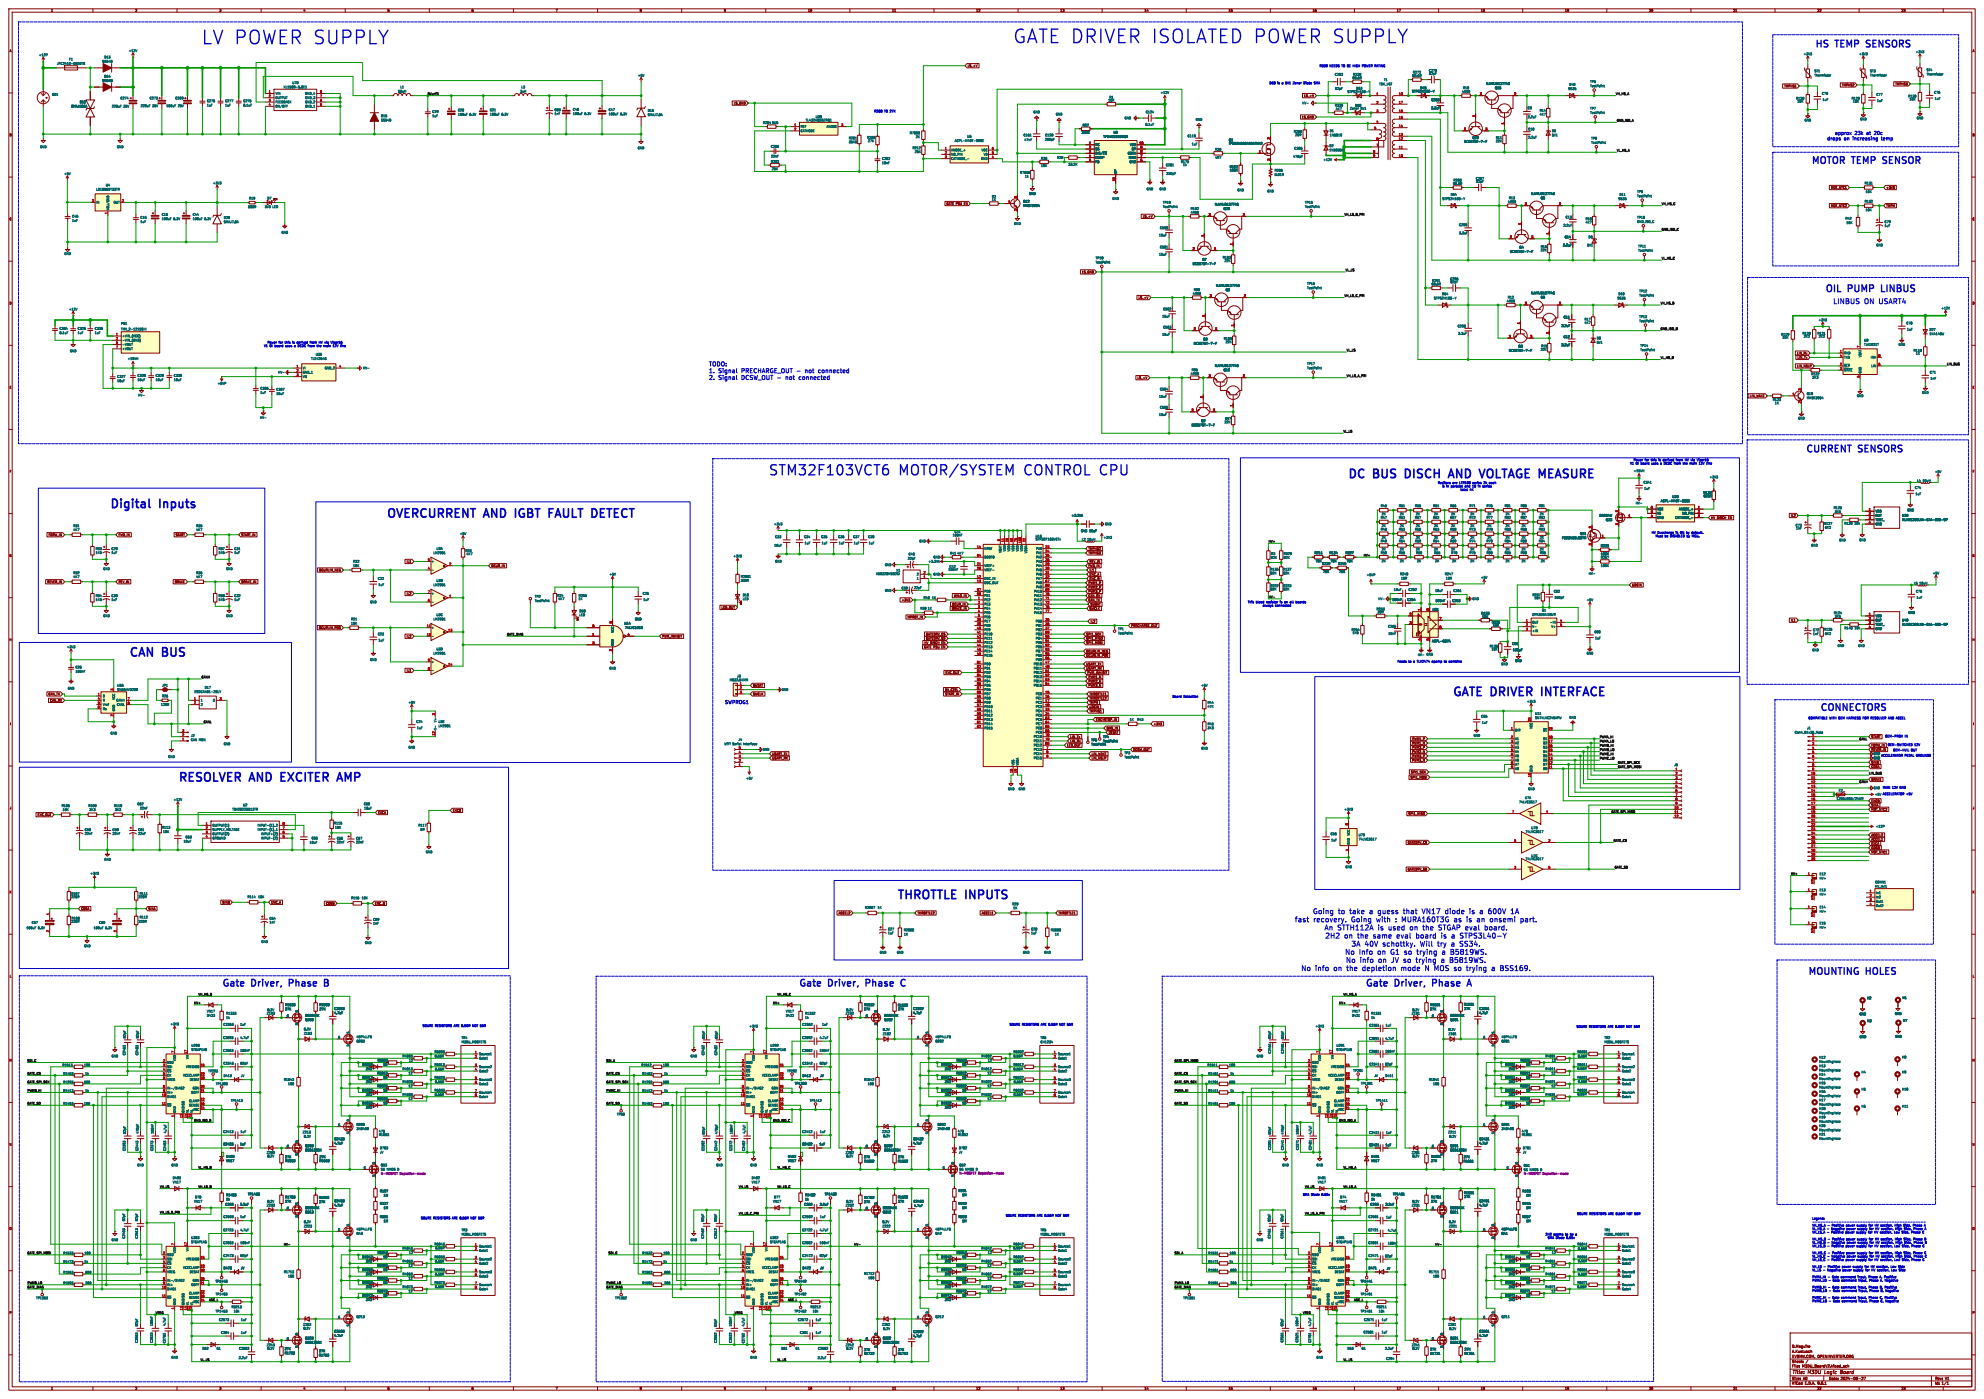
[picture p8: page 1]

GATE DRIVER ISOLATED POWER SUPPLY

R339 NEEDS TO BE HIGH POWER RATING

D68 is a 5V1 Zener Diode SMA

Power for this is derived from HV via Viper16 V1 OI board uses a DCDC from the main 12V line HV Duscharge is ON by default. Must be DISABLED by MCU. Feeds to a TLV2474 opamp to combine

STM32F103VCT6 MOTOR/SYSTEM CONTROL CPU

Resitors are LTR100 series 2k each

OVERCURRENT AND IGBT FAULT DETECT

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

OEM-SWITCHED 12V OEM-HVIL OUT COMPATIBLE WITH OEM HARNESS FOR RESOLVER AND ACCEL MAIN 12V GND THROTTLE INPUTS

RESOLVER AND EXCITER AMP

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

SMA Diode 0.55v Gate Driver, Phase B
4.7uF Q303 BSS138BK G

SOURE RESISTORS ARE 0.56R NOT 56R

8 TR2 M3DU_MOSFETS

1 GNDISO 13 VH 17 VL 14 VL 23 VREGISO 15 VCECLAMP 19 DESAT 18 GON 20 GOFF 21 CLAMP 22 SENSE 16 ASC 24 U293 STGAP1AS R4012
SDO 2 SDI 3 ~{CS} 4 CK 5 VREG 6

1 GNDISO 13 VH 17 VL 14 VL 23 VREGISO

2 SDI 3 ~{CS} 4 CK
SDO

1 GNDISO 13 VH 17 VL 14 VL 23 VREGISO 15 VCECLAMP 19 DESAT 18 GON 20 GOFF 21 CLAMP 22 SENSE 16 ASC 24 U303 STGAP1AS GND C2513 82pF R1533 100 R1473 1k

8 TR5 M3DU_MOSFETS

8 TR1 M3DU_MOSFETS R4061
2H2 seems to be a SMA Diode 0.55v

Id: 1/1 Title: M3DU Logic Board

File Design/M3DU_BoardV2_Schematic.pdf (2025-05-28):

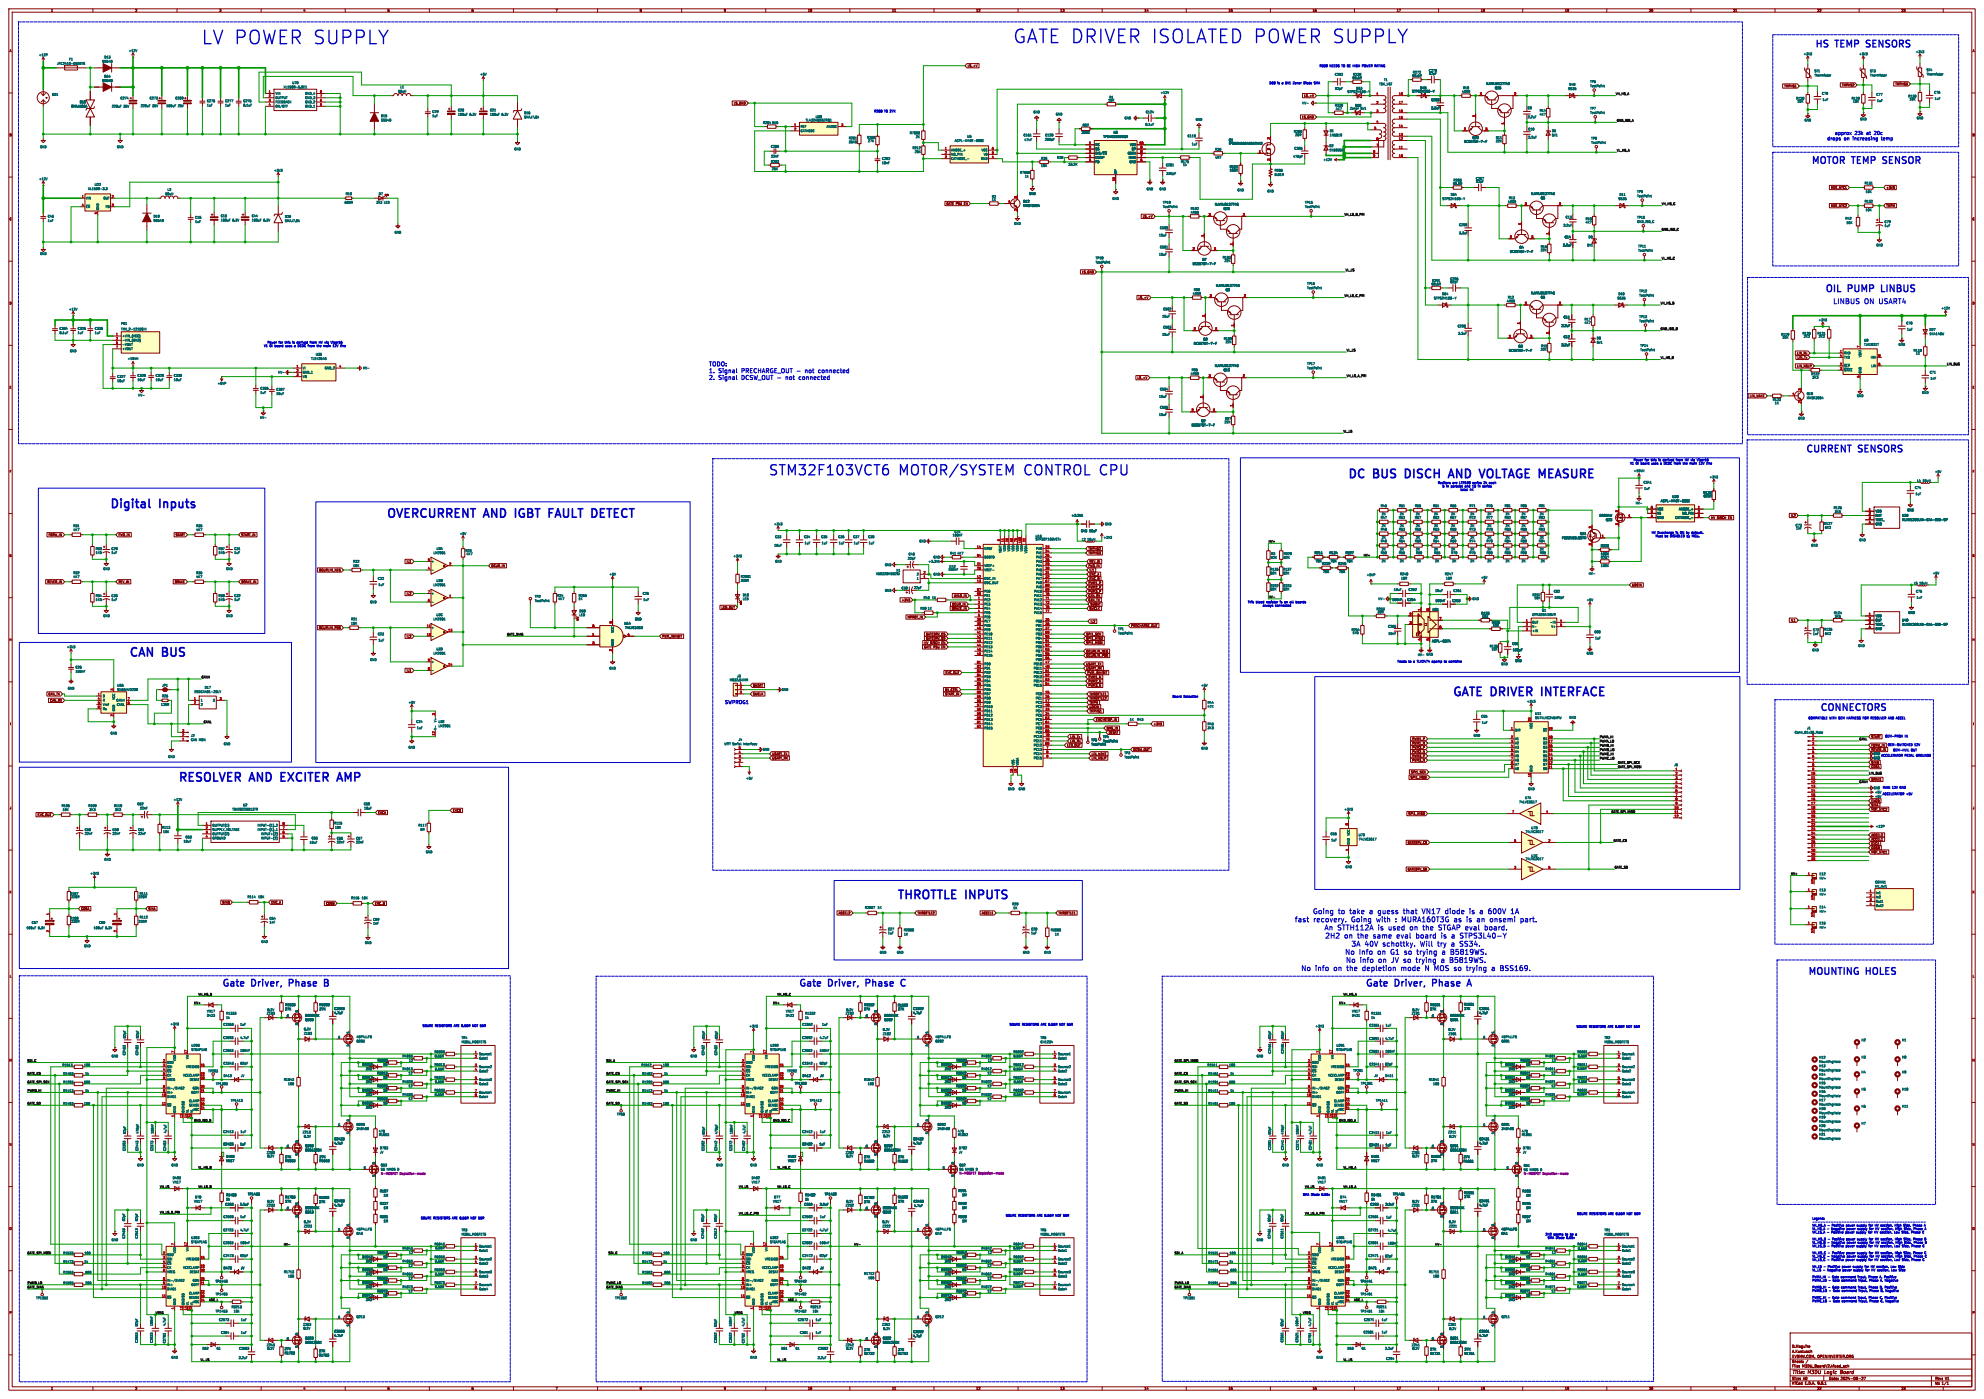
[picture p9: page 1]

GATE DRIVER ISOLATED POWER SUPPLY

OEM-SWITCHED 12V LV POWER SUPPLY

R339 NEEDS TO BE HIGH POWER RATING
10 T1 TDK_VGT

D68 is a 5V1 Zener Diode SMA

+VIN_(VCC) 1
-VIN_(GND) 2
Power for this is derived from HV via Viper16 V1 OI board uses a DCDC from the main 12V line Digital Inputs

STM32F103VCT6 MOTOR/SYSTEM CONTROL CPU

Feeds to a TLV2474 opamp to combine DC BUS DISCH AND VOLTAGE MEASURE

Resitors are LTR100 series 2k each

OVERCURRENT AND IGBT FAULT DETECT

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

SINB REVER_IN
OEM-HVIL OUT ACCELERATOR PEDAL GROUNDS

RESOLVER AND EXCITER AMP

SOURE RESISTORS ARE 0.56R NOT 56R THROTTLE INPUTS

fast recovery. Going with : MURA160T3G as is an onsemi part.

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

SOURE RESISTORS ARE 0.56R NOT 56R Gate Driver, Phase B

+3V3 C2403 4.7uF SDO 2 SDI 3 ~{CS} 4 CK 5 VREG 6

SOURE RESISTORS ARE 0.56R NOT 56R

1 GNDISO 13 VH 17 VL 14 VL 23 VREGISO 15 VCECLAMP 19 DESAT 18 GON 20 GOFF 21 CLAMP 22 SENSE 16 ASC 24 U293 STGAP1AS R1473 1k R1533 100 GND C2463 82pF C2513 82pF GND GND
SDI_C GATE_SPI_MOSI PWMB_LO

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

2H2 seems to be a SMA Diode 0.55v

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

Id: 1/1 Title: M3DU Logic Board

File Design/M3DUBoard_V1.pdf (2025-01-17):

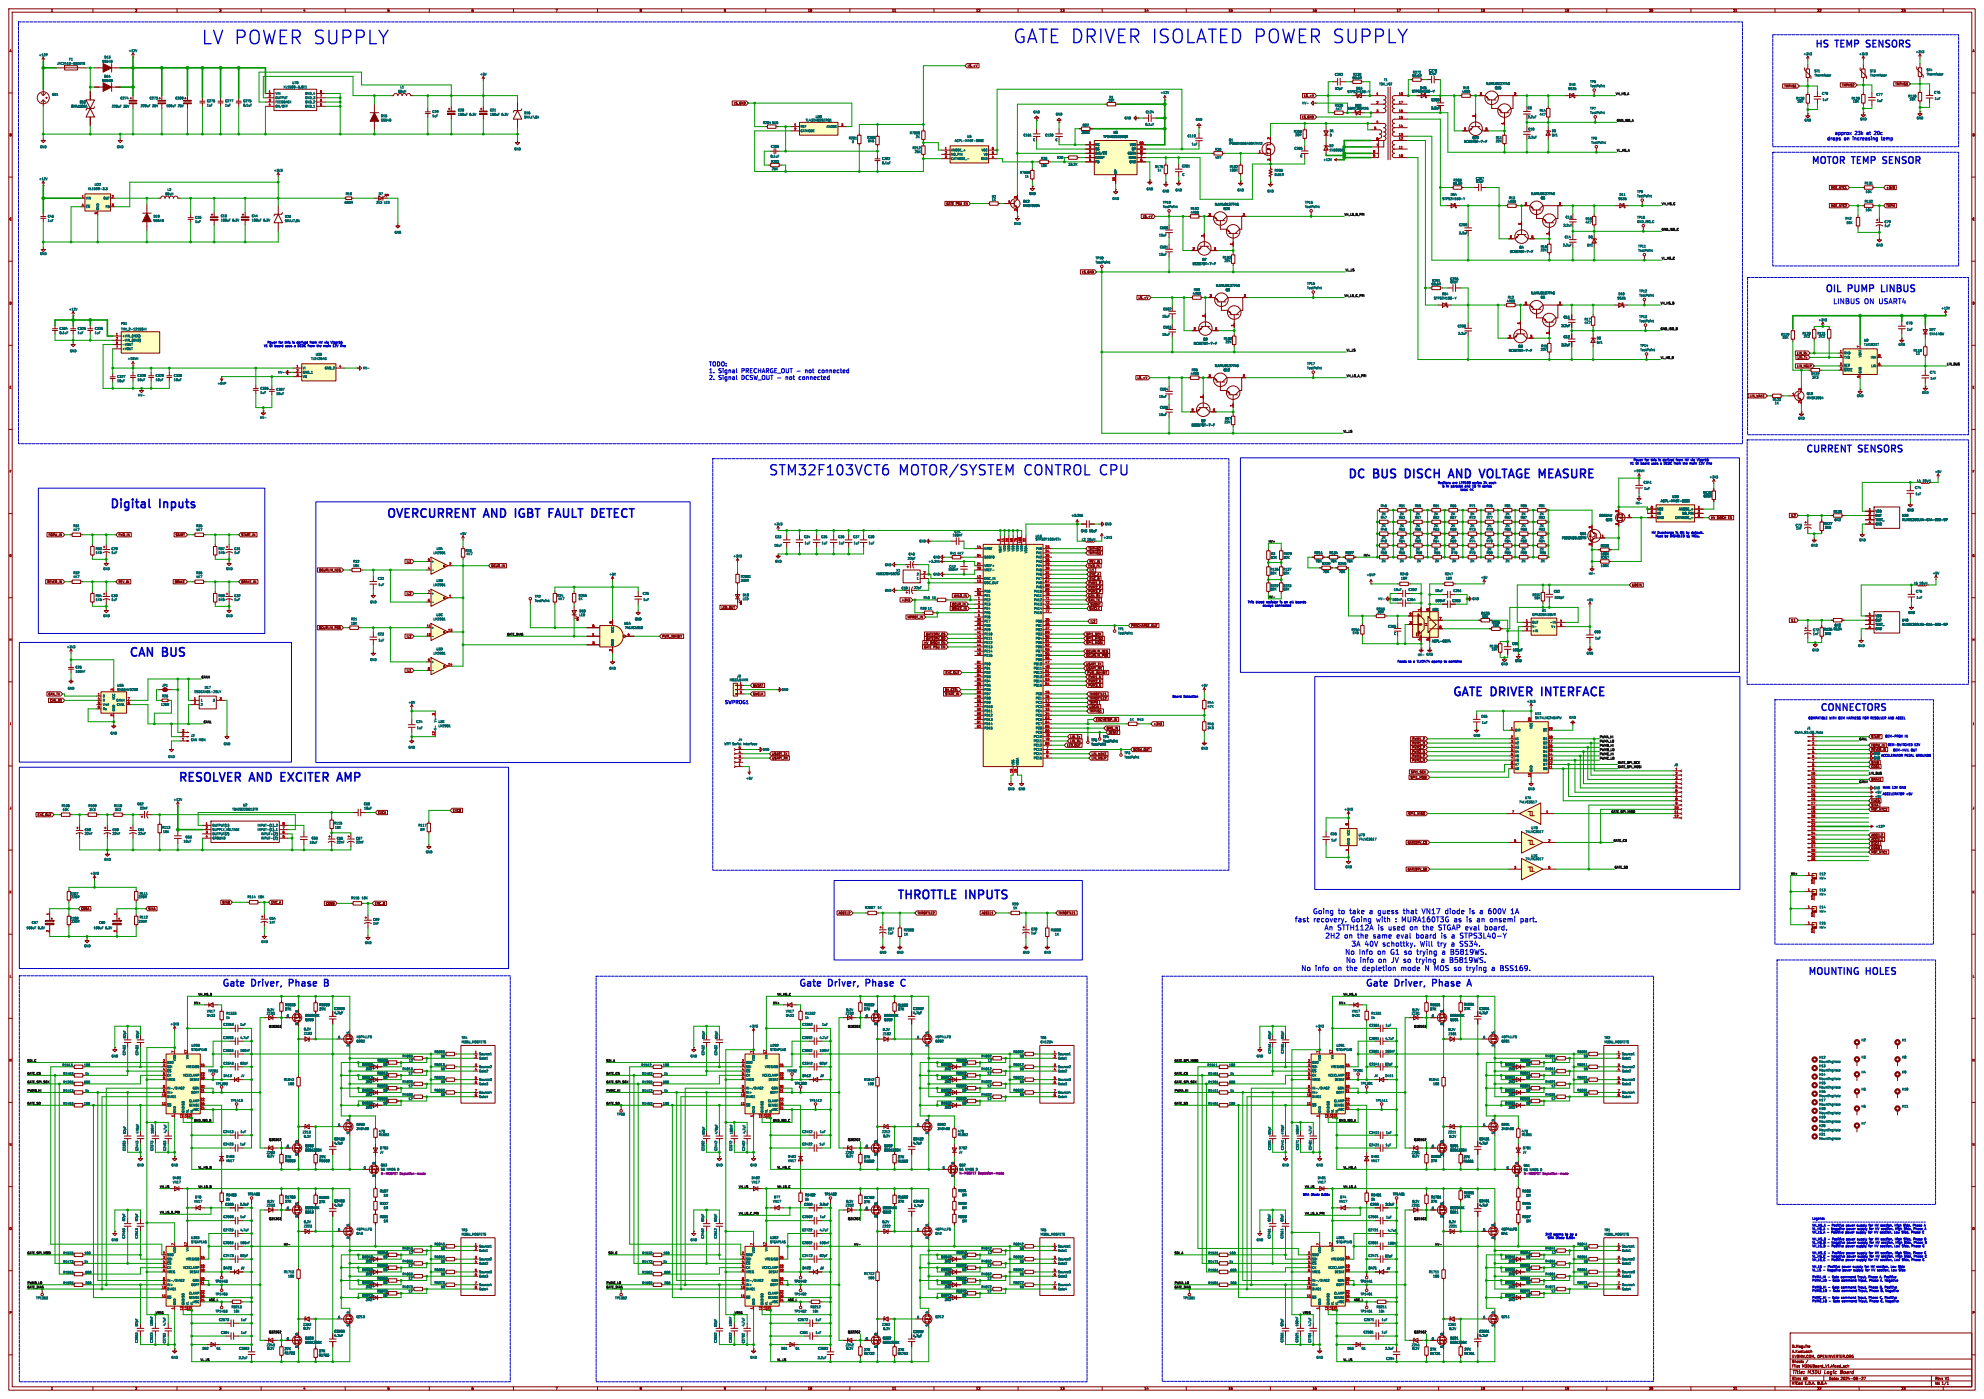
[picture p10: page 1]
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

Power for this is derived from HV via Viper16 V1 OI board uses a DCDC from the main 12V line RESOLVER AND EXCITER AMP

Feeds to a TLV2474 opamp to combine STM32F103VCT6 MOTOR/SYSTEM CONTROL CPU

DC BUS DISCH AND VOLTAGE MEASURE

Resitors are LTR100 series 2k each

OVERCURRENT AND IGBT FAULT DETECT

HV Duscharge is ON by default. Must be DISABLED by MCU. THROTTLE INPUTS

OEM-HVIL OUT COMPATIBLE WITH OEM HARNESS FOR RESOLVER AND ACCEL CONNECTORS

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

1 DIAG1 10 ~{SD} 11 GNDISO 13 VL 14 VREGISO 15 SENSE 16 VH 17 DESAT 18 VCECLAMP 19 SDO 2 GON 20 GOFF 21 CLAMP 22 VL 23 ASC 24 SDI 3 ~{CS} 4 CK 5 VREG 6 VDD

2H2 seems to be a SMA Diode 0.55v

Id: 1/1 Title: M3DU Logic Board

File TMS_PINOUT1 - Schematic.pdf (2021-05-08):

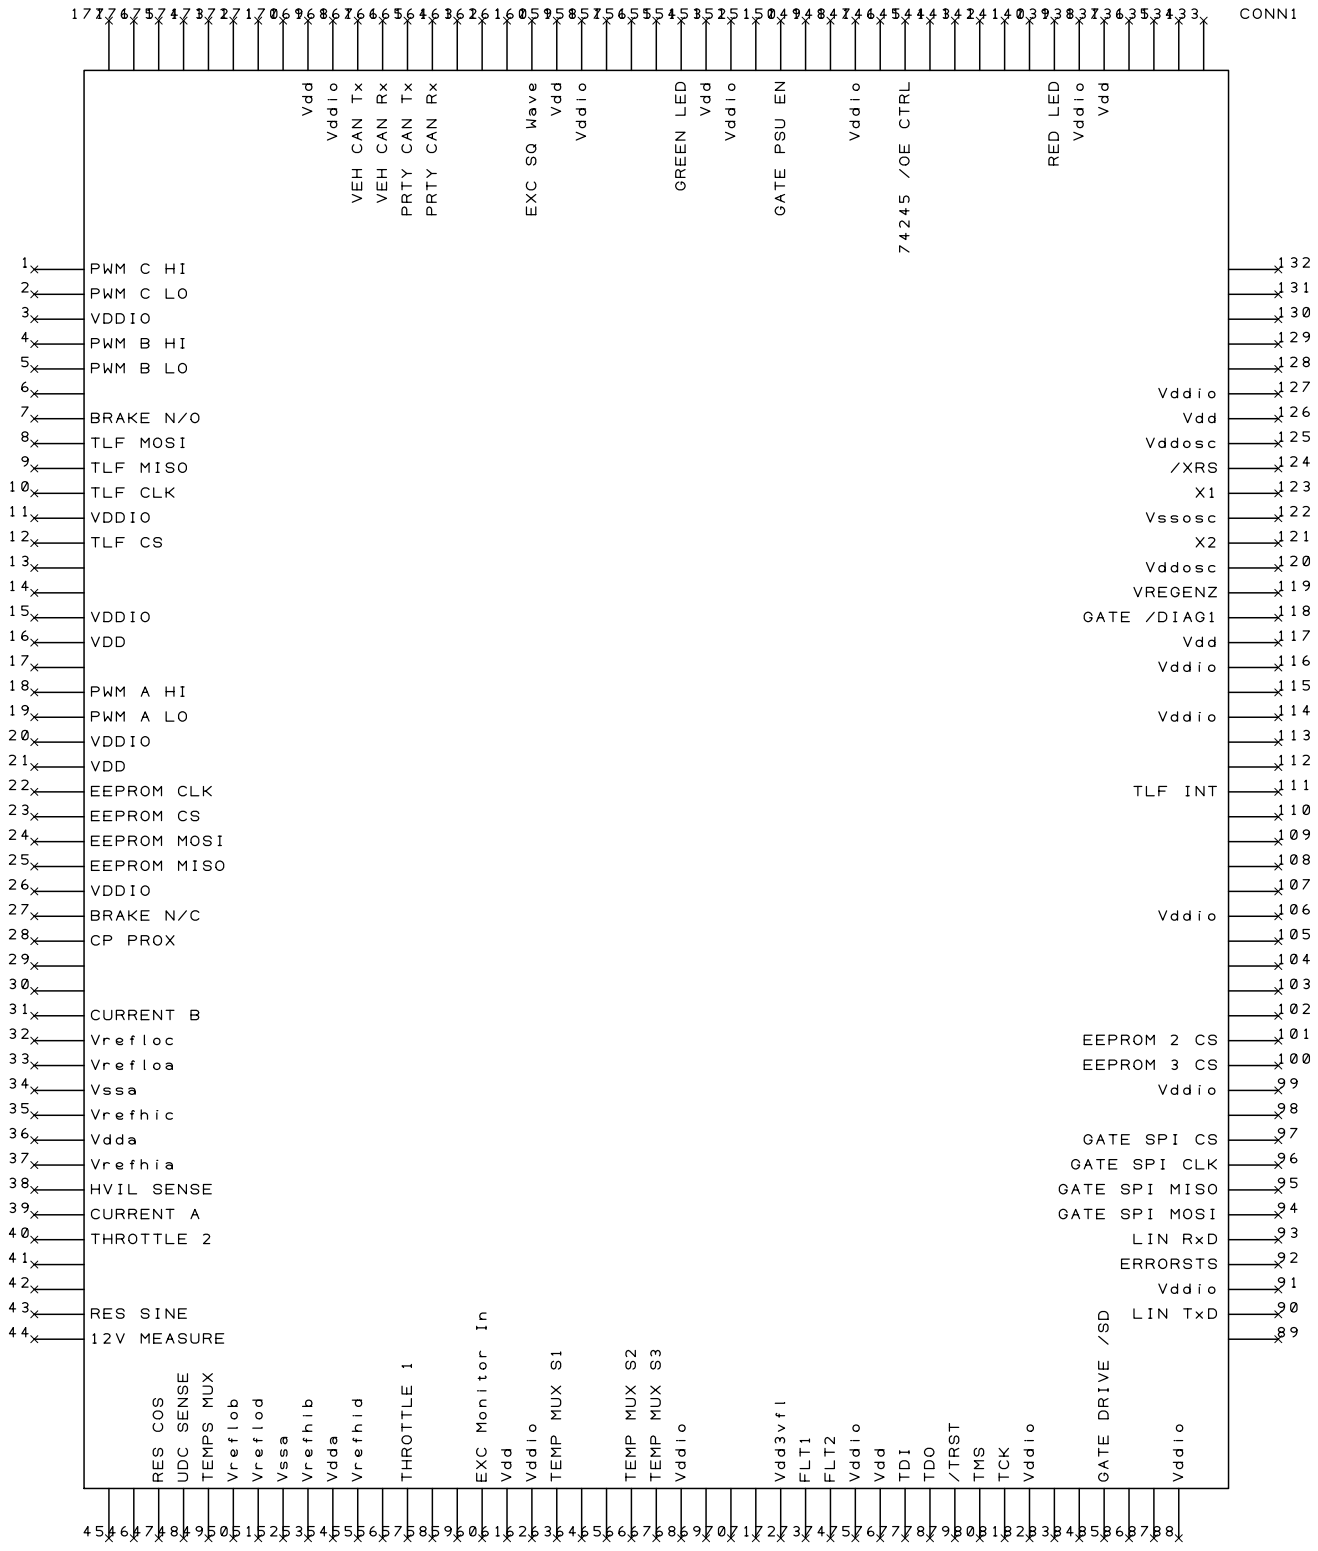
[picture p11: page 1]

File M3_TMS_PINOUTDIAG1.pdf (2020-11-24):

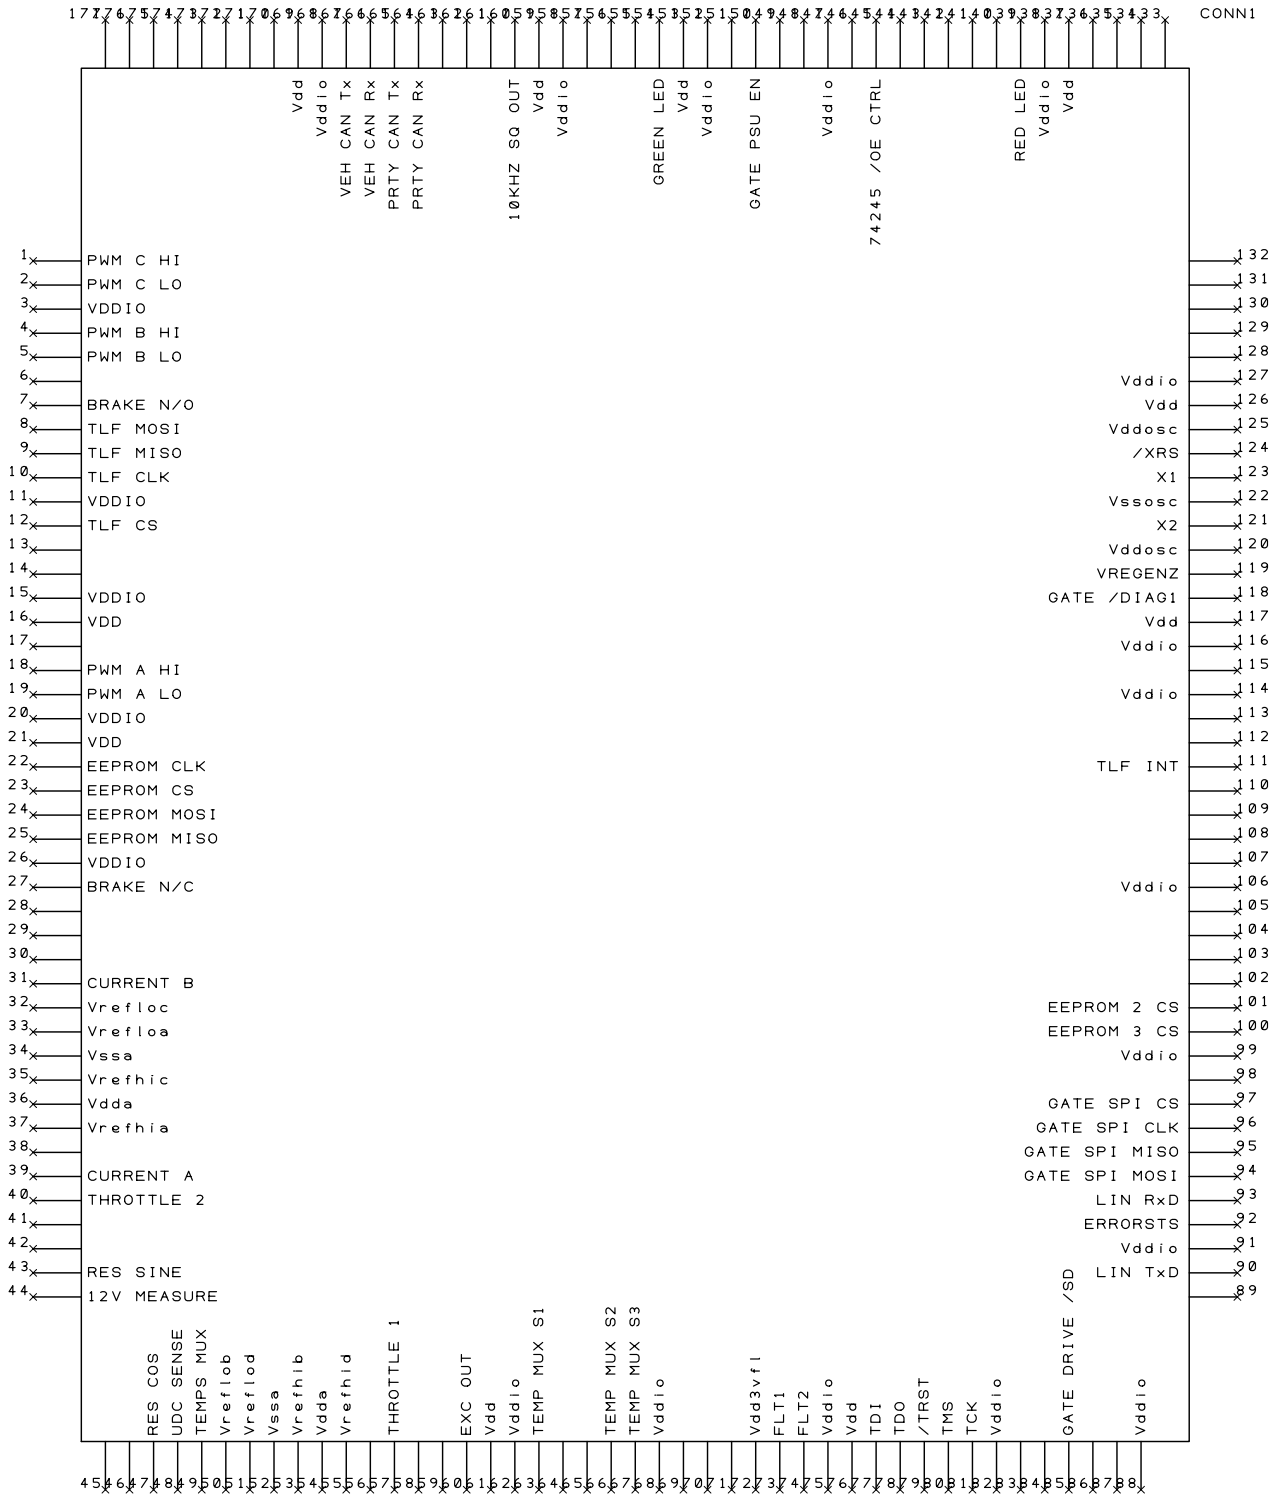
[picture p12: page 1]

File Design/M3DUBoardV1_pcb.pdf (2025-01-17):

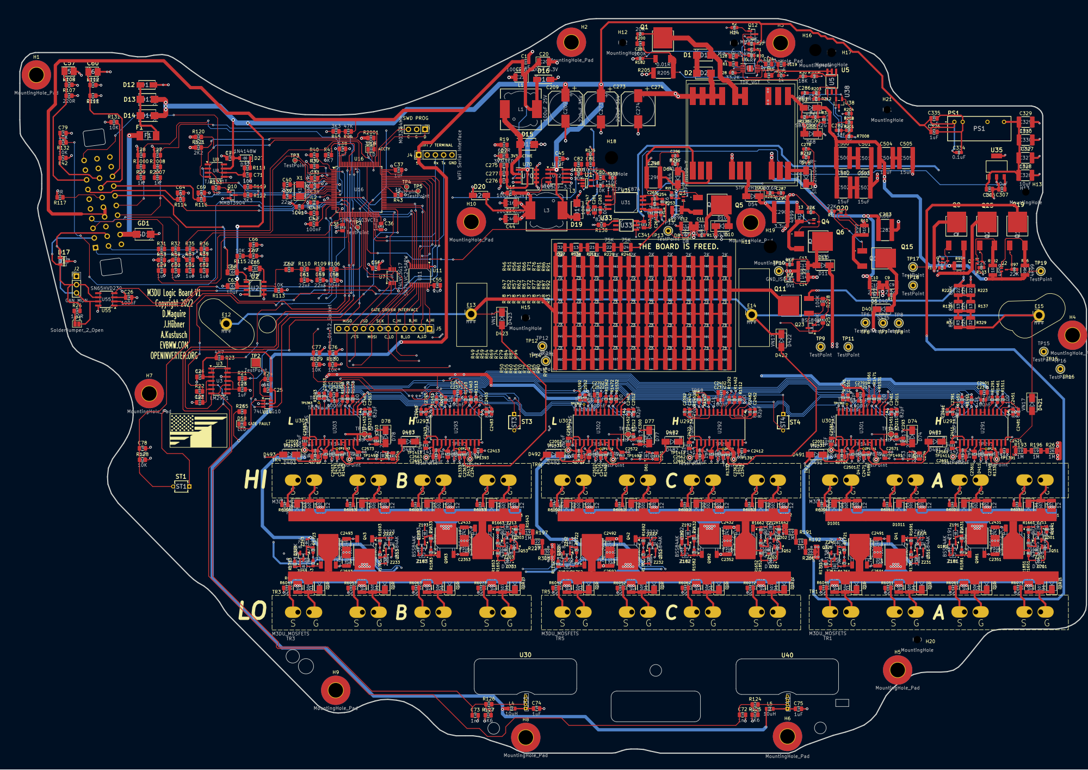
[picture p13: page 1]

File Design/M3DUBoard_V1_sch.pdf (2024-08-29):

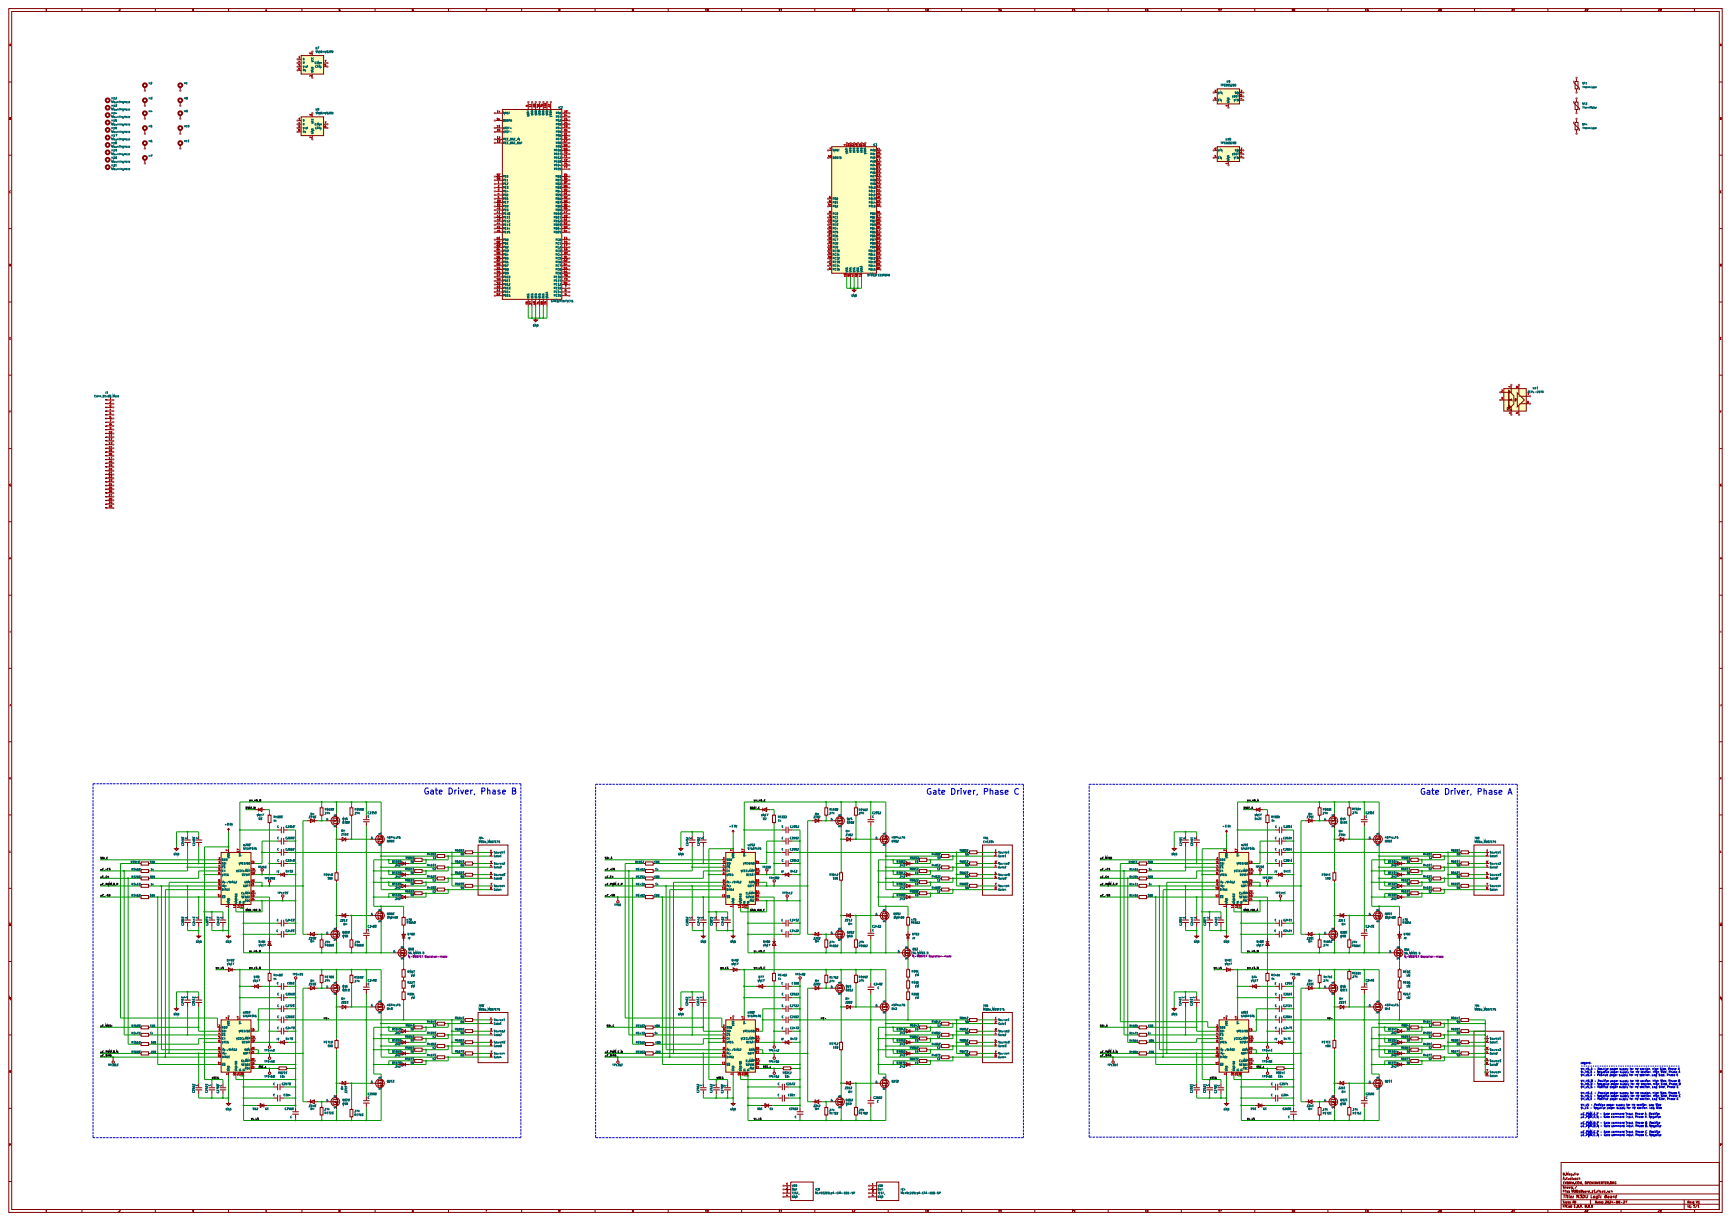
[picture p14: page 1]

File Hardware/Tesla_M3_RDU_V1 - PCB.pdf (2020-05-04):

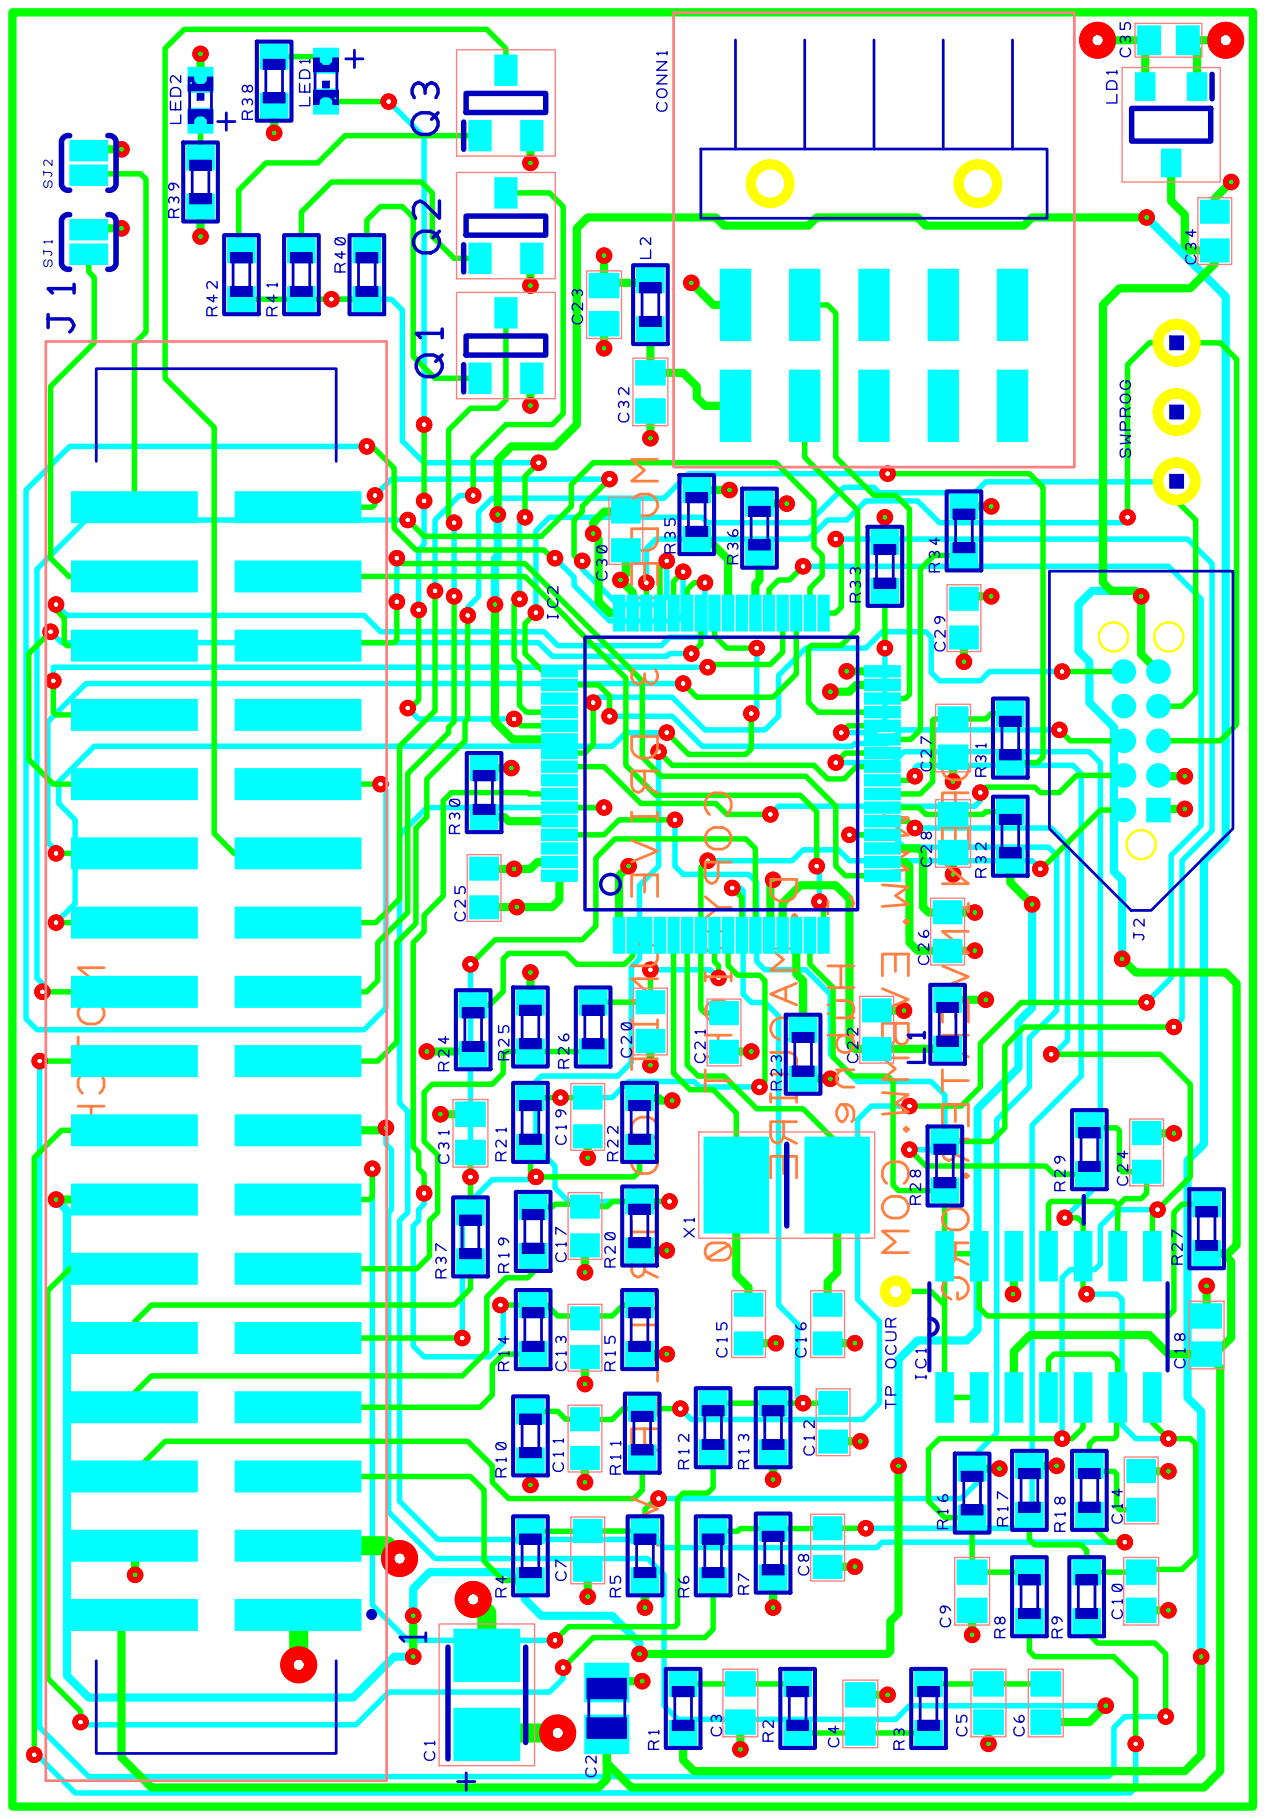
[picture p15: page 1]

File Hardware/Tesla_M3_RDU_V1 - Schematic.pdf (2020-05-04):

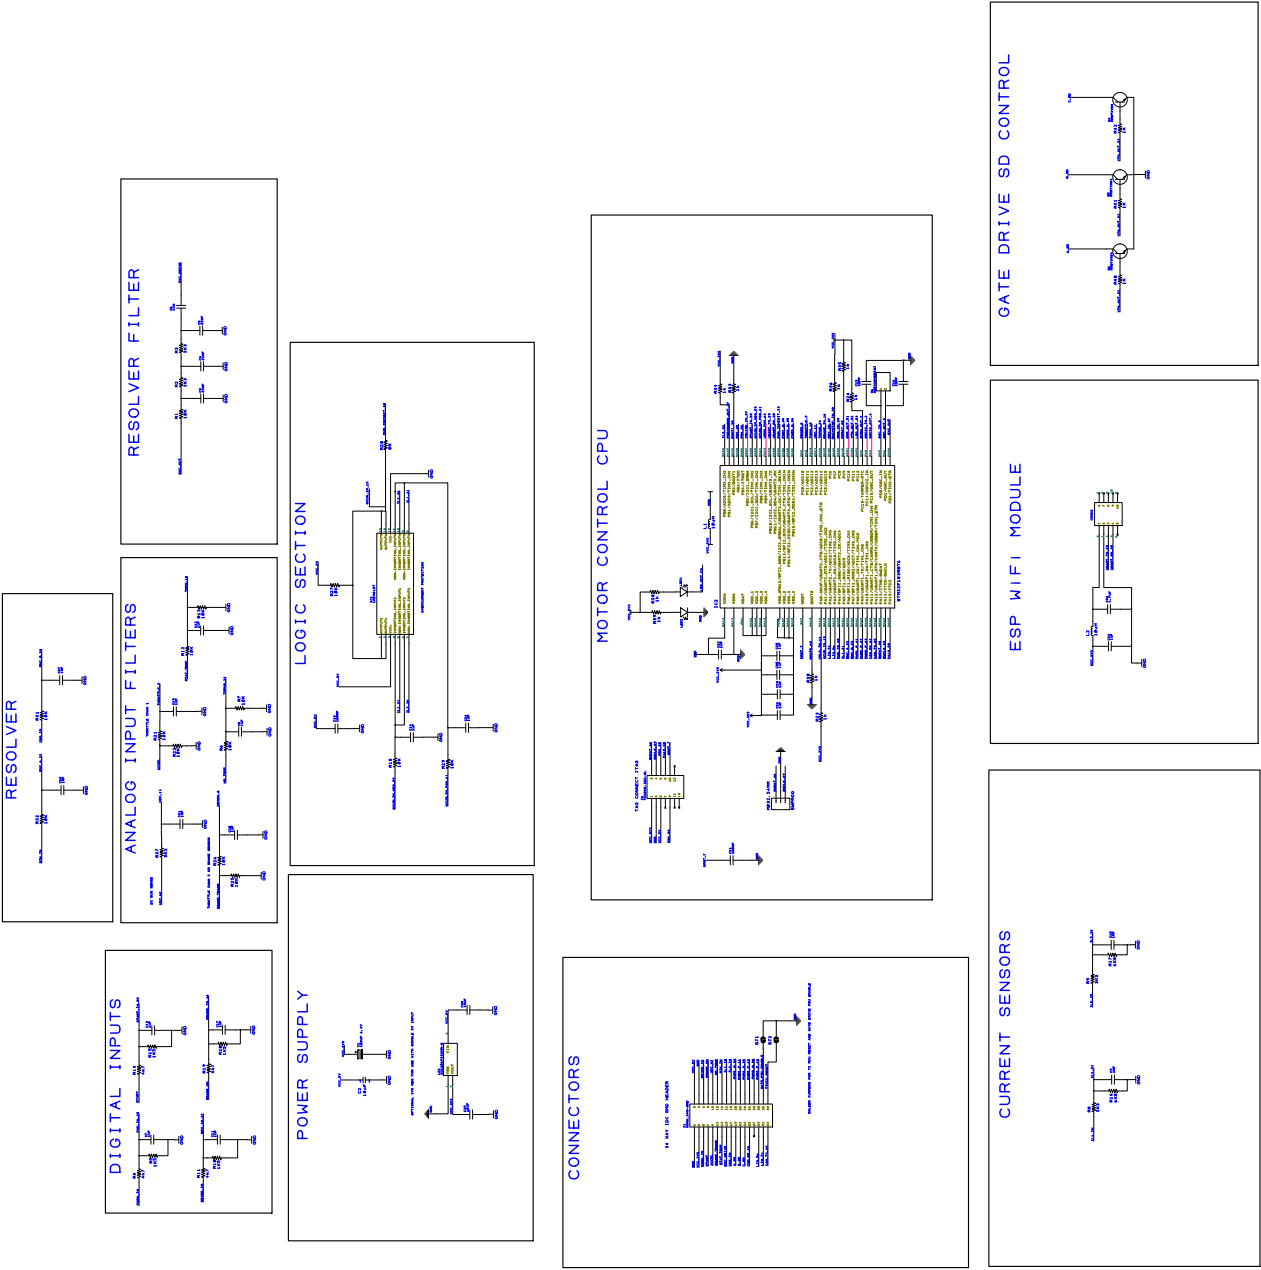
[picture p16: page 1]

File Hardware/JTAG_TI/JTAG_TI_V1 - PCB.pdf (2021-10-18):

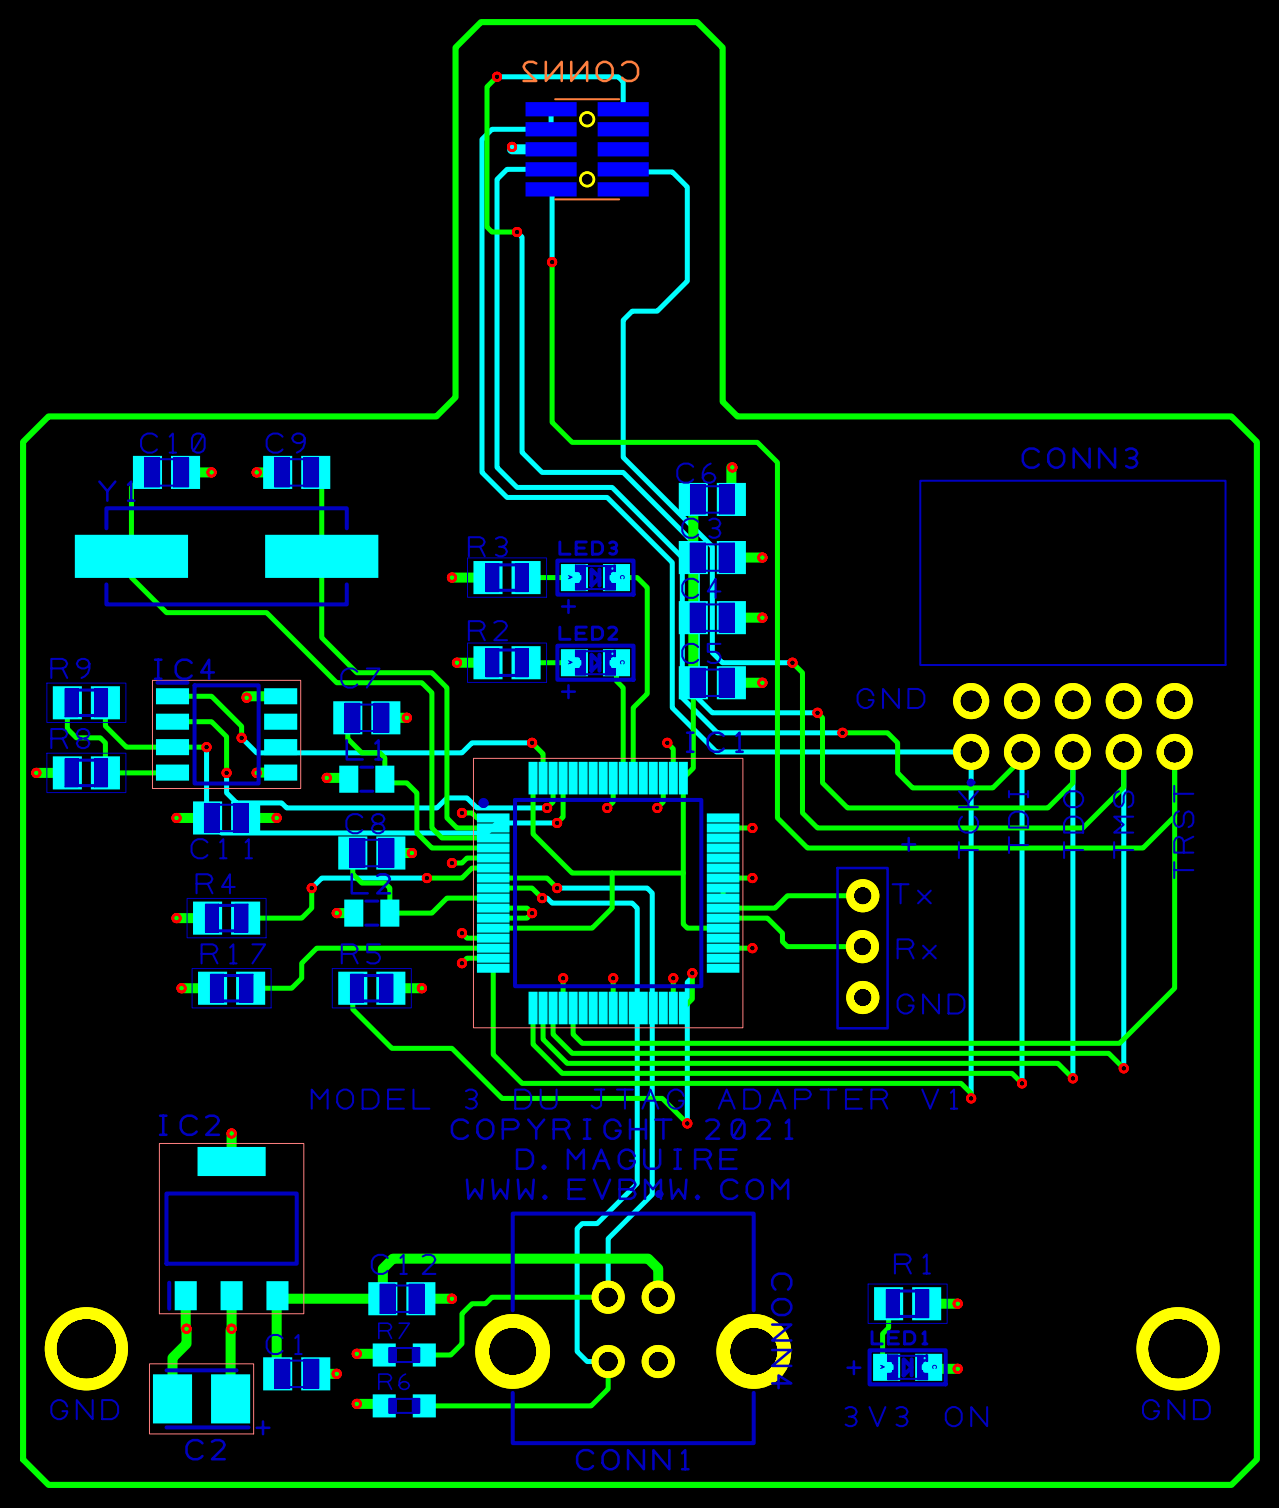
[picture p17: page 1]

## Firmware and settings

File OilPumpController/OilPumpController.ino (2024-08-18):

//
// Exercise the Tesla Model 3 oil pump over LIN
//
// Requires the LIN_master_portable_Arduino library to be installed
//
// Tested with a WEMOS LOLIN32 Lite connected to an MCP2003 LIN transceiver. The
// ~WAKE~ line is strapped to GND. RXD has 4K7 pull up to 3V3. LBUS has 1K
// pull-up to 12V via diode.
//

#include "LIN_master_HardwareSerial_ESP32.h"

// board pin definitions (GPIOn is referred to as n)
#define PIN_TOGGLE LED_BUILTIN // pin to demonstrate background operation
#define PIN_ERROR  33          // indicate LIN return status
#define PIN_LIN_RX 16          // receive pin for LIN
#define PIN_LIN_TX 17          // transmit pin for LIN
#define PIN_LIN_CS 23          // LIN transceiver chip select pin

// pause between LIN frames
#define LIN_PAUSE 100

// setup LIN node
LIN_Master_HardwareSerial_ESP32 LIN(Serial2, PIN_LIN_RX, PIN_LIN_TX, "LIN_HW");

// Tesla Oil Pump command and data request Ids in the order they appear in the
// captures
enum class PumpMessages : uint8_t
{
    Command = 0x0a,
    Status1 = 0x2a,
    Status2 = 0x32,
    Status3 = 0x30,
    Status4 = 0x31,
};

static const PumpMessages AllPumpMessages[] = { PumpMessages::Command,
                                                PumpMessages::Status1,
                                                PumpMessages::Status2,
                                                PumpMessages::Status3,
                                                PumpMessages::Status4 };

typedef std::array<uint8_t, 8> MessageData;

// Pump temperatures seem to be offset by 40 degrees Celsius
// This makes sense given typical automotive temp ranges
static const int8_t TempOffset = 40;

static void PrintError(LIN_Master::error_t error)
{
    if (error == LIN_Master::NO_ERROR)
        return;

    Serial.print("LIN Error: ");

    if (error & LIN_Master::ERROR_STATE)
        Serial.print("state ");

    if (error & LIN_Master::ERROR_ECHO)
        Serial.print("echo ");

    if (error & LIN_Master::ERROR_TIMEOUT)
        Serial.print("timeout ");

    if (error & LIN_Master::ERROR_CHK)
        Serial.print("checksum ");

    if (error & LIN_Master::ERROR_MISC)
        Serial.print("misc ");
}

static void PrintHeader()
{
    Serial.print("\r\n\nTime [ms], ");

    // PumpMessages::Command
    Serial.print("Speed_Request, ");

    // PumpMessages::Status1
    Serial.print("2A_Byte0, Flow, Pressure, Fluid_Temp, ");
    Serial.print("2A_Byte4, Pump_Temp, 2A_Byte6, 2A_Byte7, ");

    // PumpMessages::Status2
    Serial.print("32_Byte0, 32_Byte1, 32_Byte2, Motor_Speed, ");
    Serial.print("32_Byte4, 32_Byte5, 32_Byte6, 32_Byte7, ");

    // PumpMessages::Status3
    Serial.print("Supply_Voltage, 30_Byte1, 30_Byte2, 30_Byte3, ");
    Serial.print("30_Byte4, 30_Byte5, 30_Byte6, 30_Byte7, ");

    // PumpMessages::Status4
    Serial.print("31_Byte0, Supply_Current, 31_Byte2, Temp3, ");
    Serial.print("Temp4, Temp5, Temp6, 31_Byte7");
    Serial.println();
}

static void PrintMessage(PumpMessages id, const MessageData& data)
{
    switch (id)
    {
    case PumpMessages::Command:
        Serial.print(data[1]);
        Serial.print(", ");
        break;

    case PumpMessages::Status1:
        Serial.print(data[0]);
        Serial.print(", ");
        Serial.print(data[1]); // Flow
        Serial.print(", ");
        Serial.print(data[2]); // Pressure
        Serial.print(", ");
        Serial.print(data[3] - TempOffset); // Fluid_Temp
        Serial.print(", ");
        Serial.print(data[4]);
        Serial.print(", ");
        Serial.print(data[5] - TempOffset); // Pump_Temp
        Serial.print(", ");
        Serial.print(data[6]);
        Serial.print(", ");
        Serial.print(data[7]);
        Serial.print(", ");
        break;

    case PumpMessages::Status2:
        Serial.print(data[0]);
        Serial.print(", ");
        Serial.print(data[1]);
        Serial.print(", ");
        Serial.print(data[2]);
        Serial.print(", ");
        Serial.print(data[3]);
        Serial.print(", ");
        Serial.print(data[4]);
        Serial.print(", ");
        Serial.print(data[5]);
        Serial.print(", ");
        Serial.print(data[6]);
        Serial.print(", ");
        Serial.print(data[7]);
        Serial.print(", ");
        break;

    case PumpMessages::Status3:
        Serial.print(data[0] * 0.1); // Supply_Voltage
        Serial.print(", ");
        Serial.print(data[1]);
        Serial.print(", ");
        Serial.print(data[2]);
        Serial.print(", ");
        Serial.print(data[3]); // Motor_Speed
        Serial.print(", ");
        Serial.print(data[4]);
        Serial.print(", ");
        Serial.print(data[5]);
        Serial.print(", ");
        Serial.print(data[6]);
        Serial.print(", ");
        Serial.print(data[7]);
        Serial.print(", ");
        break;

    case PumpMessages::Status4:
        Serial.print(data[0]);
        Serial.print(", ");
        Serial.print(data[1] * 0.1); // Supply_Current
        Serial.print(", ");
        Serial.print(data[2]);
        Serial.print(", ");
        Serial.print(data[3] - TempOffset); // Temp3
        Serial.print(", ");
        Serial.print(data[4] - TempOffset); // Temp4
        Serial.print(", ");
        Serial.print(data[5] - TempOffset); // Temp5
        Serial.print(", ");
        Serial.print(data[6] - TempOffset); // Temp6
        Serial.print(", ");
        Serial.print(data[7]);
        break;
    }
}

// call once
void setup()
{
    // indicate background operation
    pinMode(PIN_TOGGLE, OUTPUT);

    // indicate LIN status via pin
    pinMode(PIN_ERROR, OUTPUT);

    // Turn on the transceiver
    pinMode(PIN_LIN_CS, OUTPUT);
    digitalWrite(PIN_LIN_CS, 1);

    // open LIN interface
    LIN.begin(19200);

    // for output (only) to console
    Serial.begin(115200);
    while (!Serial)
        ;

    PrintHeader();
} // setup()

// call repeatedly
void loop()
{
    static uint8_t speed = 0x00;
    static String  inputBuffer;

    int newChar = Serial.read();
    while (newChar >= 0)
    {
        if (newChar == '\r' || newChar == '\n')
        {
            if (inputBuffer.length() > 0)
            {
                speed = constrain(inputBuffer.toInt(), 0, 255);
                inputBuffer.clear();
            }
        }
        else
        {
            inputBuffer += char(newChar);
        }

        newChar = Serial.read();
    }

    Serial.print(millis());
    Serial.print(", ");

    for (auto id : AllPumpMessages)
    {
        LIN_Master::error_t error;
        MessageData         data;
        if (id == PumpMessages::Command)
        {
            // The first byte of the command is always 0xff in Tesla captures
            // changing it seems to do nothing
            data[0] = 0xff;
            data[1] = speed;
            error = LIN.sendMasterRequestBlocking(
                LIN_Master::LIN_V2, static_cast<uint8_t>(id), 2, data.data());

            if (error)
            {
                PrintError(error);
            }
            else
            {
                PrintMessage(id, data);
            }
        }
        else
        {
            error = LIN.receiveSlaveResponseBlocking(
                LIN_Master::LIN_V2,
                static_cast<uint8_t>(id),
                data.size(),
                data.data());

            if (error)
            {
                PrintError(error);
            }
            else
            {
                PrintMessage(id, data);
            }
        }

        // indicate status via pin
        digitalWrite(PIN_ERROR, error);

        if (id == PumpMessages::Status4)
            Serial.println();

        // reset state machine & error
        LIN.resetStateMachine();
        LIN.resetError();
    }

    // wait a bit. Toggle pin to show CPU load
    uint32_t delayStart = millis();
    while (millis() - delayStart < LIN_PAUSE)
    {
        digitalWrite(PIN_TOGGLE, !digitalRead(PIN_TOGGLE));
    }
} // loop()

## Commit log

2021-09-22 Document details of the M3 inverter JTAG connector
    Compiled from these forum posts:
    https://openinverter.org/forum/viewtopic.php?p=14739#p14739
    https://openinverter.org/forum/viewtopic.php?p=19474&sid=5ffd673af86430a29c9e03ae60ca0871#p19474
    and from board inspection.
    The pin number is different from the previous notes but
    matches the Hirose datasheet pin numbering.
    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
2021-10-01 LIN captures of Tesla FW control of M3 Oil Pump
    The change contains captures of the LIN interface connecting
    the main M3 inverter to the oil pump. They were captured
    with Saleae Logic 2.3.37 from power on of the inverter. The power supply was low (circa 11V) and the pump appeared stalled.
    Startup_Oil_Pump_Disconnected - No oil pump connected
    Startup_Oil_Pump_Connected - Normal operation from cold
    Startup_Oil_Pump_Hairdrier-1 - Warm the oil pump casing
    for about 30 seconds with a hair drier.
    Startup_Oil_Pump_Hairdrier-2 - Warm the oil pump casing for 2-3 minutes with a hair drier.
2021-10-03 Fix CAN GPIO error
    [TMS320F28377D_M3_PinMap.ods]
2021-10-18 Add USB to JTAG adapter design files
    [JTAG_TI_V1_bom.xls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]
2022-02-10 Start a list of test points on the M3 inverter board
    A basic list of test points from inspection and measurement of
    the board and gleaned from Damien's videos.
    [M3-Inverter-Test-Points.ods]
2022-02-13 Add details of main inverter wiring harness
    This expands the rear inverter connector pinout to include the
    wiring harness colours found on the Tesla harness (1067968-
    02-E). Also, add details of the connector pin numbering and
    physical layout. With these changes it is possible to test and
    modify Tesla wiring harnesses more easily.
    Add details of missing Stator Temp + and - signal.
    Remove the PDF in favour of an ODS spreadsheet to allow
    easier future revision.
    Tests:
    - Cross check against Tesla wiring harness with a multimeter
    [M3_RearDU_OEM_Pinout.ods]
2022-03-20 Fix ADC input for 12V supply monitoring
    The pin for 12V DC supply monitoring is not ADCIN14 but
    ADCINC4 instead.
    It seems that ADCIN14 may be used for monitoring a 1.65V
    mid-rail reference and calibrating ADCs (per TI
    documentation). Not 100% certain so leaving this line blank
    for now.
    - Power the inverter from a variable bench supply and load a
    program to display the output of ADCINC4. Log values at
    different supply voltages to determine the gain of 205.88
    counts per volt.
    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
    [TMS320F28377D_M3_PinMap.ods]
2022-09-23 Fix swapped Vehicle and Party CAN bus signals
    Running a TI C2000 example transmitting using the CANA
    peripheral (GPIO_5_CANRXA and GPIO_4_CANTXA) results in
    output on the Vehicle CAN interface not Party CAN as
    expected.
    This swaps the pins in the PinMap spreadsheet but does not
    update M3_TMS_PINOUTDIAG1.pdf
    - Cross-check official Tesla M3 wiring harness and connector
    with wiring diagram 2019.1_Model3-SOP3-1LHDandRHD
    from the Tesla Service Manual.
    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
    [TMS320F28377D_M3_PinMap.ods]
2023-01-28 Add pinouts
    Added pin details for resolver, oil pump and throttle pedal.
    [M3_RearDU_OEM_Pinout.ods]
2023-03-11 Correct Phase B current sensor pin
    Correct msitake in pin assignment for the phase B current sensor output.
    [TMS320F28377D_M3_PinMap.ods]
2023-03-19 Add temp sensor data
    A first attempt at calibrating some of the temperature sensors in the Model 3 rear drive unit inverter and motor.
    [RDU_Temp_Sensors.ods]
2023-03-25 Add details of gate drive PSU ready
    The isolated gate drive PSU centered around T1 reports
    back when it is running via GPIO83. This signal shows
    up on the opto-isolator U7 at TP28 and TP43 near the
    MCU.
    Also document TP133 and TP134 which relate to resolver exciter output.
    [M3-Inverter-Test-Points.ods, TMS320F28377D_M3_PinMap.ods]
2024-08-15 Add schematic gate driver
    Add a very early schematic of the M3 drive unit gate driver section. NOT FINAL!
    [M3DUBoard_V1.kicad_sch]
2024-08-18 Add an Arduino sketch to control the Tesla oil pump
    This Arduino sketch connects to the oil pump over LIN using the
    hardware serial on an ESP32. According to the captures taken of
    the LIN of a running inverter there is 1 outgoing command and
    4 status requests. The outgoing command appears to be the
    desired speed of the pump. The incoming status messages are
    currently not understood so are just printed out as hex values.
    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
2024-08-18 Decode oil pump temp, voltage and current status
    Lots of fields had the same value after an overnight cold soak with a 40 degree offset from the drive-unit case temp. Running the pump causes some temps to increase but other stay the same.
    Supply voltage and current tested with a bench power
    supply. Values track measured values quite accurately.
2024-08-18 Output oil pump status in CSV format
    To allow easier analysis of the oil pump status fields output in
    CSV. Also change the update to have no delay between requesting
    each status value but maintain 100ms between each group of
    requests.
2024-08-18 Decode oil pump operating status fields
    Run the oil pump for about a minute at full speed and
    capture the log in short-run.ods. This allows various
    status parameters to be graphed against time.
    It looks like 30_Byte3 ramps up first and the graph
    follows the pitch which can be heard from the motor.
    Label this as Motor_Speed.
    The 2A_Byte1 values ramp up next and this reflects the
    observed behaviour when emptying the old oil out of
    my drive unit where there was a perceptible delay
    between the motor spinning up and the fluid flow. This
    value ramps down with a lag after the Speed_Request
    returns to 0.
    The 2A_Byte2 value looks like the best guess for the
    pump pressure. It peaks a bit after the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
    [short-run.ods]
2024-08-28 Update Gate Driver schematic
    [M3DUBoard_V1.kicad_sch]
2024-10-24 Update schematic with gate psu progress
2025-01-17 Update PCB design and Schematic to latest
2025-02-08 Add 3d step file of V1
    Note this board has errors.
2025-05-28 Add V2 board schematic
    V2 board schematic with corrections and all component values now filled out.
2025-07-29 Add latest V2 Schematic and PCB
2025-09-29 Add V3 schematic and board layout
2025-11-18 Add pinout for V3 Logic board
2025-12-03 Add DXF laser OEM board scan
    [tesla model 3 inberter pcb v2.dxf]
2026-02-01 Add V3.2 Schematic and PCB
2026-02-26 Add FDU Gate SPI
2026-03-07 Free The Board
    [M3DUBoard_V3_2_BOM_JLC.xls, M3DU_BoardV3_2.kicad_sch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]
2026-08-02 Pin 23 relabeled Not Connected -> Active Disch Disable +12V, reflecting active-discharge-disable feature. Added editable HTML pinout generator
